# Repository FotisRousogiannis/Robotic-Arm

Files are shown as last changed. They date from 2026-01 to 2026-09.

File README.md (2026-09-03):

# Robotic Arm — Διπλωματική Εργασία

Σχεδίαση και ανάπτυξη ενός **6-DOF ρομποτικού βραχίονα**, από τη μηχανική
κατασκευή (3D printing) και τα ηλεκτρονικά, μέχρι το λογισμικό ελέγχου.
Το repository αποτελεί το επίσημο αποθετήριο της διπλωματικής εργασίας και
συγκεντρώνει το σύνολο του υλικού: μηχανολογικά σχέδια, hardware,
ηλεκτρικά/ηλεκτρονικά, τεκμηρίωση και αναφορές (reports).

---

## Στόχος του Project

Η μελέτη, σχεδίαση και υλοποίηση ενός λειτουργικού ρομποτικού βραχίονα
χαμηλού κόστους, με:

- Κατασκευή εξαρτημάτων μέσω **3D εκτύπωσης (FDM)**
- Κίνηση αρθρώσεων με **servo κινητήρες υψηλής ροπής (40 kg·cm)**
- Έλεγχο μέσω **Raspberry Pi 4** και οδηγό servo **PCA9685 (I²C, 16 κανάλια)**
- Τεκμηρίωση σε τρεις άξονες: μηχανολογικό, ηλεκτρικό και λογισμικό

---

## Δομή του Repository

```
.
├── Robotic_Arm_Project/
│   ├── 3D printing/          # STL / 3MF αρχεία προς εκτύπωση ανά εξάρτημα
│   │   ├── Rotating Base/    #   περιστρεφόμενη βάση
│   │   ├── Big Base/         #   κύρια βάση
│   │   ├── Bone 1/, Bone 2/  #   βραχίονες (links)
│   │   ├── Gears/            #   γρανάζια
│   │   ├── Timing Belt/      #   σύστημα ιμάντα
│   │   ├── Bearing holders/  #   στηρίγματα ρουλεμάν
│   │   ├── Electronics Holder/
│   │   ├── End Effector/     #   αρπάγη (gripper)
│   │   └── Caps/
│   ├── Hardware/             # Λίστα ηλεκτρικών εξαρτημάτων & datasheets
│   ├── Electrical/           # Σχηματικά διαγράμματα (schematics)
│   └── Documentation/        # Ρυθμίσεις slicer & τεκμηρίωση λογισμικού
├── Reports/                  # Mechanical / Electrical / Software reports (PDF)
├── Papers/                   # Σχετική βιβλιογραφία & ROS stack overview
└── README.md
```

---

## Hardware

### Τροφοδοσία
- 1× KUAIQU SPS-C3010 ρυθμιζόμενο τροφοδοτικό 30 V / 10 A / 300 W
- 2× XY5008E DC-DC Buck converter (CC/CV, 6–55 V, 5 A)

### Έλεγχος & Λογική
- 1× Raspberry Pi 4 Model B (4 GB)
- 1× PCA9685 — 16-channel 12-bit PWM servo driver (I²C)

### Κινητήρες (Servo)
Χρησιμοποιούνται servo **GXservo 40 kg·cm (MG)**:

| Άρθρωση | Πλήθος | Τύπος |
|---|---|---|
| Base | 1× | 40 kg·cm, 180° |
| Bone 1 | 4× | 40 kg·cm, 180° |
| Bone 2 | 4× | 40 kg·cm, 270° |
| End effector | 3× | 40 kg·cm, 180° |

### Καλωδίωση
- Σήμα: 3-pin, 22 AWG
- Ισχύς: 2-pin (κόκκινο/μαύρο), 18 AWG

> Αναλυτικά: [`Robotic_Arm_Project/Hardware/Electrical Components.md`](Robotic_Arm_Project/Hardware/Electrical%20Components.md)

---

## Κατασκευή (3D Printing)

Όλα τα δομικά εξαρτήματα βρίσκονται ως αρχεία `.stl` / `.3mf` στον φάκελο
`Robotic_Arm_Project/3D printing/`. Οι ρυθμίσεις slicer (Orca Slicer) που
χρησιμοποιήθηκαν βρίσκονται στο
`Robotic_Arm_Project/Documentation/`.

---

## Τεκμηρίωση & Αναφορές

Στον φάκελο `Reports/` υπάρχουν τρεις αναφορές:
- **Mechanical Report** — μηχανολογικός σχεδιασμός
- **Electrical Report** — ηλεκτρικό/ηλεκτρονικό υποσύστημα
- **Software Report** — λογισμικό ελέγχου

---

## Κατάσταση / Roadmap

- [x] Μηχανολογικός σχεδιασμός & 3D εκτύπωση εξαρτημάτων
- [x] Επιλογή ηλεκτρικών/ηλεκτρονικών εξαρτημάτων
- [x] Σχηματικά διαγράμματα
- [ ] Λογισμικό ελέγχου (kinematics, control)
- [ ] Ολοκλήρωση & δοκιμές συναρμολογημένου βραχίονα

---

## Άδεια χρήσης

Ακαδημαϊκή εργασία. Για χρήση/αναπαραγωγή επικοινωνήστε με τον συγγραφέα.

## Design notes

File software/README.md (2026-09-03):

# Software

The arm's software is organized in two tracks so you can move fast now
and still build the proper stack for the thesis.

```
software/
├── firmware/       # ESP32 firmware — the on-board control per segment PCB.
│   └── segment_controller/   PCA9685 + TCA9548A + AS5600, serial protocol.
├── tools/          # Standalone scripts — NO ROS needed. Quick bench test
│   └── servo_test.py   of a servo/gearbox straight off a PCA9685.
└── ros2_ws/        # ROS 2 workspace — the host-side coordination stack.
    └── src/robotic_arm_driver/
```

The real control is **distributed**: each segment PCB runs
`firmware/segment_controller` on its ESP32 (servo drive + encoder
feedback), and the ROS 2 host coordinates all segments. See
[`../docs/ARCHITECTURE.md`](../docs/ARCHITECTURE.md) for the topology.
`tools/servo_test.py` is only for quick bench checks before the boards
are wired in.

## Track 1 — Quick hardware tests (no ROS)

Goal right now: **verify the wrist and its gearboxes** before building
Link 1. `tools/servo_test.py` drives the PCA9685 directly.

### On the Raspberry Pi — Ubuntu Server (once)
Ubuntu Server has no `raspi-config`; enable I²C via the firmware config:
```bash
sudo nano /boot/firmware/config.txt      # add:  dtparam=i2c_arm=on
sudo apt install -y i2c-tools python3-pip
sudo usermod -aG i2c $USER               # then log out/in
sudo reboot
# after reboot:
pip install adafruit-circuitpython-pca9685 adafruit-blinka
i2cdetect -y 1                           # should show PCA9685 at 0x40
```

> Note: in the final design the ESP32 on each PCB drives the PCA9685, not
> the Pi. This direct-from-Pi path is only for quick bench testing of a
> servo/gearbox before the boards are in the loop.

### Test sequence (start gentle!)
```bash
cd software/tools

# 1. Center the wrist servos (find your real centers first):
python3 servo_test.py center --channels 8 9 10 11 --min 0 --max 270

# 2. Move ONE servo a little and confirm direction:
python3 servo_test.py set --channel 9 --angle 135 --min 0 --max 270

# 3. Slow, small sweep to watch a gearbox for binding/backlash:
python3 servo_test.py sweep --channel 9 --min 0 --max 270 \
        --start 120 --end 150 --step 2 --dwell 0.1

# 4. Differential check (wrist pitch/roll from 2 servos):
python3 servo_test.py diff --a 9 --b 10 --pitch 15 --roll 0   # pure pitch
python3 servo_test.py diff --a 9 --b 10 --pitch 0  --roll 15  # pure roll

# 5. Release when done:
python3 servo_test.py release --channels 8 9 10 11
```

> Runs in **SIMULATION mode** (prints pulses) on any machine without the
> PCA9685 libs, so you can dry-run commands on your laptop first.

**Safety:** keep a hand on the power switch; stop immediately if a servo
stalls, buzzes, or a gearbox binds. Increase travel only once direction
and limits are confirmed.

Record the real centers / min / max you find — they become the
calibration values in the ROS 2 config below.

## Track 2 — ROS 2 stack

`ros2_ws/src/robotic_arm_driver` — a ROS 2 (rclpy) node that subscribes
to `/joint_commands` (`sensor_msgs/JointState`, degrees) and drives the
servos, with **differential mixing** for the base and wrist.

### Build & run (on the Pi, ROS 2 installed)
```bash
cd software/ros2_ws
colcon build --packages-select robotic_arm_driver
source install/setup.bash

# Wrist-only bring-up:
ros2 launch robotic_arm_driver wrist_test.launch.py

# Command the wrist pitch to 15 deg from another terminal:
ros2 topic pub --once /joint_commands sensor_msgs/msg/JointState \
  '{name: ["wrist_pitch"], position: [15.0]}'
```

Calibration lives in `config/wrist_test.yaml` (wrist only) and
`config/servo_config.yaml` (full arm). Update the channel numbers,
centers, gains and pulse limits from what you measured in Track 1.

See [`../docs/ARCHITECTURE.md`](../docs/ARCHITECTURE.md) for the DOF map,
differential mixing math, and roadmap.

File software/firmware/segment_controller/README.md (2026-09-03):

# Segment Controller (ESP32 firmware)

One firmware for every per-segment PCB (base, wrist, ...). Each board runs
the local control loop for its joints:

- **PCA9685** → servo PWM
- **TCA9548A** → I²C mux selecting one **AS5600** encoder at a time
- **AS5600** → true joint-angle feedback (all share address `0x36`, so the
  mux is required)

It exposes a simple **serial protocol** (USB, 115200 baud) so you can test
the wrist and gearboxes right away, before any host/ROS integration.

## Build & flash (PlatformIO)
```bash
cd software/firmware/segment_controller
pio run                 # build
pio run -t upload       # flash the ESP32
pio device monitor      # open serial monitor @115200
```

Configure the board via `-DSEGMENT_NAME=...` in `platformio.ini` and the
wiring/limits in `include/config.h`.

## Serial commands
| Command | Action |
|---|---|
| `?` | print segment info (axes, channels) |
| `P <axis> <deg>` | set target angle for one axis (open-loop servo) |
| `H` | home all axes (servo center) |
| `E` | print all encoder angles (deg) |
| `M <a> <b> <p> <r>` | differential mix test: servos a,b from pitch/roll |
| `R <axis>` | release one axis servo (stop PWM) |

### Example wrist bring-up
```
?                 # confirm wiring
E                 # read encoders — move a joint by hand, watch it change
P 0 90            # command axis 0
M 0 1 15 0        # differential: pure pitch on servos ch0/ch1
M 0 1 0 15        # differential: pure roll
E                 # compare commanded vs actual (encoder) angle
```

## Calibration workflow
1. Flash, open the monitor, send `?` and `E`.
2. Turn each joint by hand and confirm the right encoder responds and the
   direction is correct (set `encoder_invert` in `config.h` if not).
3. Note the encoder reading at the mechanical home → set `encoder_offset`.
4. Command small servo angles with `P`; find the real `pulse_min/max` and
   `servo_min/max_angle` for each axis.
5. Copy the confirmed numbers into `config.h` (and the ROS 2 configs).

## Roadmap
- [ ] Closed-loop position control on the ESP32 (PID: encoder → servo)
- [ ] Host link via **micro-ROS** (`env:esp32-microros` in `platformio.ini`):
      each ESP32 is a ROS 2 node; host runs the micro-ROS Agent
      (`ros2 run micro_ros_agent micro_ros_agent udp4 --port 8888`).
- [ ] Publish `/<seg>/joint_states`, subscribe `/<seg>/joint_commands`

> Firmware/PCB work is on hold until the boards are built — the serial
> firmware above is enough for current bench testing.

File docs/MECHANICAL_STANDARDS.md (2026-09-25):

# Mechanical Standards

Standardization rules so every part interfaces cleanly and future parts
"just fit". Apply these across all segments. Items marked ❓ need
confirmation against existing parts.

---

## 0. Material assignment policy
**Default PLA+; PC only where extreme strength/heat is needed; TPU for
flexible parts.** Rule: *carries the load/torque or gets hot → PC; else PLA+.*

| Material | Parts |
|---|---|
| **PC** | all gears (planetary sun/planet/ring — esp. output stage; bevel), planet carrier, output/spline hubs, load-critical links, anything next to the servo (heat) |
| **PLA+** | covers, electronics holders, sensor mounts, brackets, non-load structure, prototypes |
| **TPU** | gripper pads/fingertips, feet, cable strain-relief, dampers/bushings |

> ⚠️ PLA+ **creeps** under sustained load and softens near heat (Tg ~60°C).
> Keep it off gears, shafts/hubs, and the main load-bearing links.

## 1. Fasteners
- **Socket head cap screws, ISO 4762 (DIN 912)**, metric, throughout.
- **M3** = primary · **M4 / M5** = structural / high-load.
- 3D-printed parts: **brass heat-set inserts (M3)** — never a screw straight
  into plastic.

## 2. Bearings (deep-groove ball, 2RS sealed)
Standardize on the set already in use:

| Bearing | bore × OD × W (mm) | Use (actual) |
|---|---|---|
| 6002 2RS | 15 × 32 × 9 | **planet gears** (each planet rotates on a 6002) |
| 6005 2RS | 25 × 47 × 12 | **shafts / joint output axes** (Ø25) |
| 6902 2RS | 15 × 28 × 7 | ❓ (thin-section, TBD) |
| 6004 2RS | 20 × 42 × 12 | ❓ TBD |
| 6208 2RS | 40 × 80 × 18 | ❓ likely base main rotation, TBD |

## 3. Shafts / hubs
- **Shaft Ø = bearing bore**, tolerance **h7** (slip/press per fit needed).
- Large bores (≥20) → **hub-in-bore** (bearing = joint pivot; hub rotates on
  inner race), leaving the bore **hollow for cable routing**.
- A **flat / D-cut** where a set-screw lands, to prevent slip.

| Element | Ø (=bore) | Bearing |
|---|---|---|
| output / joint shaft | 25 | 6005 |
| planet gear | 15 | 6002 |
| base main rotation | 40 | 6208 (TBD) |

## 4. Gears — global rules
- **Pressure angle: 20°** everywhere (non-negotiable for meshing).
- **Module: keep to few values.** Gears of different module DO NOT mesh.
  - Planetary gears: **helical, normal module mₙ = 1, helix 30°** (actual).
  - **Min ~17 teeth** on a pinion for spur; helical tolerates fewer (sun is
    16T helical — OK thanks to the helix angle raising virtual tooth count).
- **Center distance**: `C = module × (z₁ + z₂) / 2`.
- Printed material: **PETG** ok, **Nylon (PA)** preferred for loaded gears.

### 4a. Planetary gearbox (per joint) — ACTUAL design
2-stage, **1:6 × 1:6 = 1:36**. **Helical gears, 30° helix angle.**

| Element | Teeth | Hand | File |
|---|---|---|---|
| Sun | 16 | L | Sun Helical Gear (16L@30.00) |
| Planet (×3) | 32 | R | Healical Gear (32R@30.00) |
| Ring | 80 | R | Ring Gear |

- **Normal module mₙ = 1**, **helix angle β = 30°**, 20° PA.
- Ratio = 1 + 80/16 = **6.0** ✅ · 3 planets: (16+80)/3 = 32 ✓
- Helix hand: sun L, planet R (external mesh = opposite), ring R (internal =
  same as planet) ✓
- Transverse module mₜ = mₙ/cos β = 1/cos30° = **1.1547**.
  Pitch diameters (d = mₜ·z): sun 18.48 · planet 36.95 · ring 92.38 mm.
  Center distance sun↔planet = (18.48+36.95)/2 = **27.7 mm**
  = (ring−planet)/2 ✓ consistent.
- Helical gears create **axial thrust** — deep-groove bearings absorb it;
  keep it in mind for shaft location.
- Housing parts (CAD): Ring Gear, Planet Carrier, Planet Carrier Rotating
  Base, Cap, Servo holder, Servo Cap, servo arm cap.

### 4b. Bevel gears (differentials)
- **1:1 miter**, 90°, 20° PA, pitch diameter **Ø100 mm**.
- Bore = DIN 5480 internal spline (mounts on the gearbox output shaft).
- Current **module 1, z100** is **undersized for 5 kg** (tooth force ~740 N
  operating needs ~55 mm face at m1 — impossible).
- **Target spec (5 kg): module 2.5, z40 (keeps Ø100), face ~15–18 mm,
  PC** (available; strong + high Tg ~147°C) or PA-CF, face ~18 mm + firmware torque limit. See MECHANICAL_ANALYSIS.md.

## 5. Couplings & interfaces
- **Output shaft → bevel gear**: spline (see §9a) — carries actuator torque
  into the differential.
- **Gearbox housing → arm body**: ISO 9409-1 flange (see §9b).
- **Servo output spline: 25T** (standard for 35–40 kg standard-size servos;
  spline Ø ≈ 5.9 mm — confirm by counting teeth / checking the horns) →
  standard **25T spline hub / disc horn** as the servo interface everywhere.
- **servo → sun gear**: uses the **stock metal servo horn** (25T, included
  with the servo). The sun gear (or a printed adapter) bolts onto the horn
  through its screw holes — no separate hub needed. Standardize the sun/
  adapter to match the horn's bolt pattern.
- **shaft ↔ shaft**: **clamp-type coupling** (no backlash) sized to shaft Ø,
  preferred over set-screw for precision.

## 6. Differential flanges
- **Common bolt pattern**: proposed **6 × M3 on PCD 30 mm**, identical on base
  and wrist → interchangeable flanges.
- **Spigot centering** (a locating lip) for alignment — not screws alone.

## 7. Tolerances & fits
- Shaft/bearing: **h7** shaft into bearing bore.
- Gear backlash (printed): target **0.10–0.15 mm** (set as CAD offset).

## 8. File naming convention (gears & shafts)
Encode the spec in the filename so mating parts are obvious:
```
spur_m1.5_z22_b25_PA20.stl      spur, module 1.5, 22T, bore 25, PA 20°
bevel_m1.5_z20_90deg_b25.stl    bevel, module 1.5, 20T, 90°, bore 25
planet_m1.0_z24_sun12_ring60.stl
shaft_d25_L120_h7.stl           shaft Ø25, length 120, h7
```

## 9. Output interfaces — ISO

Two distinct interfaces per actuator:
```
servo → planetary(1:36) → OUTPUT SHAFT ──[spline]──► BEVEL gear → differential
                          gearbox housing ──[FLANGE ISO 9409-1]──► arm body (mount)
```

### 9a. Output shaft → bevel gear (torque path)
Drives the differential's bevel gear — **backlash & centering are critical**
here (differential mixing degrades with play), so **spline preferred over
key**.
**All parts are 3D printed** → the bevel gear's bore is a **printed internal
DIN 5480 spline** that slides onto the shaft's splined section. No press fit
(cracks/creeps printed plastic), no coupling, no locking device needed.

The shaft has two sections: a plain **Ø25 k6 journal** for the 6005 bearing,
and a **splined section** where the bevel gear mounts (spline is NOT at the
bearing seat).

### DIN 5480 spline values — from SplineCALC (DIN preferred pair)
**Designation: `DIN 5480 – 25 × 1.25 × 18 × 9H/8f`** (30° PA)

| Parameter | Shaft (external, 8f) | Hub / bevel bore (internal, 9H) |
|---|---|---|
| Reference diameter dB | 25.000 | 25.000 |
| Module m | 1.25 | 1.25 |
| Teeth z | 18 | 18 |
| Addendum mod. x | **+0.450** | **−0.450** |
| Pitch diameter d | 22.500 | 22.500 |
| Base diameter db | 19.486 | 19.486 |
| Tip diameter da | 24.750 | 22.500 |
| Root diameter df | 22.444 | 25.250 |
| Engagement length Le | 15 mm | 15 mm |
| Backlash j (min/max) | 0.038 / 0.284 mm | — |

- Chosen over m1/z24: **module 1.25 = coarser, stronger teeth** (better given
  the printed-gear strength concern).
- The 9H/8f pair already includes backlash (j = 0.038–0.284 mm); for 3D print
  add a touch more if it binds.
- Export the profile from SplineCALC (DXF shaft / DXF hub) straight into
  Fusion, or enter the values above.
- **Axial retention** (so the bevel doesn't slide off) — **as built**:
  a **heat-set insert (M4/M5) in the shaft end** + an **ISO 4762 screw +
  washer** through the bevel/cap that clamps it against a printed shoulder.
  Printed-friendly, no groove needed. (Alt: circlip DIN 471 Ø25.)
- Bearing seat: **Ø25 k6**; general tolerances ISO 2768-m; end chamfers 1×45°.

> Stay metric (DIN 5480, module-based). Avoid inch (McMaster) splined shafts
> — they force an inch-bore bearing at this seat.

> Spline chosen over a parallel key because it is printed anyway (no
> machining cost) and gives less backlash — important for clean pitch/roll
> decoupling in the differential. A DIN 6885 key remains a simpler fallback.

### 9b. Flange → arm body (mounting)
Mounts/reacts the gearbox housing to the arm structure — **ISO 9409-1**.
**Default: ISO 9409-1-50-4-M6**
- PCD **50 mm**, **4 × M6** (ISO 4762)
- centering **spigot H7/h7** (alignment by fit, not screws)
- Torque check (worst case 73.5 N·m): 73.5/0.025 = 2940 N ÷ 4 = **735 N/bolt**
  → M6 ample ✅
- Heavier option: **ISO 9409-1-63-6-M6** (PCD 63, 6 × M6)

Use the same flange across base / wrist / links for interchangeability.

## 10. Standard parts — sourcing (CAD)
Pull ready, dimensioned models into Fusion; model only custom parts.

| Part | Standard | Source (Fusion) |
|---|---|---|
| Bearings (6002/6005/6208…) | ISO | McMaster (Insert → McMaster-Carr) / TraceParts / Misumi |
| Screws (M3–M6 socket head) | ISO 4762 | McMaster / Fusion fastener lib / TraceParts |
| Parallel key 8×7 | DIN 6885-1 | TraceParts / Misumi |
| Precision shaft Ø25 k6 | ISO 286 | McMaster / Misumi (configurable) |
| Heat-set inserts M3 | — | McMaster |
| **ISO 9409-1 flange** | ISO 9409-1 | **model in Fusion** (spec, not a purchased part) |
| Gears (planetary/bevel) | — | model in Fusion (per §4) |

## 11. I²C address map (electronics, for reference)
| Device | Address |
|---|---|
| PCA9685 (PWM) | 0x40 |
| ADS1115 (ADC) | 0x48 |
| TCA9548A (mux) | 0x70 |
| AS5600 (encoder) | 0x36 (behind mux) |

---

## Confirmed
- [x] Planetary: helical, mₙ=1, 30° helix, sun 16 / planet 32 (×3) / ring 80
- [x] Planet count: 3

## Confirmed (cont.)
- [x] Servo interface: stock metal 25T horn drives the sun gear
- [x] Servo spline: 25T

## Open items to confirm
- [ ] Output torque path: parallel key vs direct-through-flange
- [ ] Flange size: ISO 9409-1-50-4-M6 (default) vs 63-6-M6
- [ ] Bevel gear module/teeth (needs differential envelope)
- [ ] Placement of remaining bearings (6208 / 6004 / 6902)
- [ ] Planet gear face width (for tooth-stress recheck)

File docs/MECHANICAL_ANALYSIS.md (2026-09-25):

# Mechanical Analysis

Engineering analysis of the actuator/drivetrain against the design targets.
All figures are estimates for design guidance; validate on hardware.

## Inputs (from BOM / standards)
| Parameter | Value |
|---|---|
| Servo | QY3240MG, ~40 kg·cm ≈ **3.9 N·m stall**, continuous rotation |
| Servo free speed | ~300°/s (≈50 rpm) |
| Gearbox | 2-stage planetary, **1:6 × 1:6 = 1:36** |
| Efficiency (2 stages) | ~0.8 assumed |
| Differential | pitch uses **2 actuators** (torques add) |
| Arm self-weight | 5 kg, CoM ≈ 0.5 m |
| Target reach | 1.0 m |
| **Target payload** | **5 kg @ 1 m** |

## 1. Output speed & torque (per actuator, 1:36)
- Speed: 300 / 36 = **8.3°/s** (90° in ~11 s)
- Torque stall: 3.9 × 36 × 0.8 = **~112 N·m**
- Torque continuous (≈stall/3): **~37 N·m**

Differential (pitch, ×2):
| | per actuator | differential (×2) |
|--|---|---|
| Stall | 112 N·m | **214 N·m** |
| Continuous | 37 N·m | **75 N·m** |

## 2. Torque required for 5 kg @ 1 m (worst case, horizontal)
| Component | Moment |
|---|---|
| Payload 5 kg × 1.0 m | 49 N·m |
| Arm 5 kg × 0.5 m | 24.5 N·m |
| **Total** | **73.5 N·m** |

## 3. Does 1:36 meet it?
| Mode | Available (diff) | vs 73.5 N·m |
|---|---|---|
| Stall (momentary) | 214 N·m | SF ≈ 2.9 ✅ |
| Intermittent (~50% duty, pick-place) | ~112 N·m | SF ≈ 1.5 ✅ |
| Continuous hold (stall/3) | 75 N·m | SF ≈ 1.0 🟠 marginal |

**Conclusion:** 1:36 is the **right reduction** for 5 kg pick-and-place.
Lower ratios can't even hold the arm's own weight continuously; higher
ratios (1:48) hold better but are too slow (~6°/s) and worsen gear stress.
Continuous indefinite holding of 5 kg is marginal → needs a holding
strategy (§6).

### Reduction trade-off (continuous payload @1 m)
| Ratio | Output speed | Continuous payload | Gear stress |
|---|---|---|---|
| 1:18 | 17°/s | ~1.3 kg | medium |
| 1:24 | 12.5°/s | ~2.6 kg | high |
| **1:36** | 8.3°/s | ~5 kg | 🔴 very high |

## 4. Gear tooth loading (the critical issue)
Output stage transmits the full torque. Tangential force at the
planet↔ring mesh (pitch r_ring = 46.2 mm, 3 planets sharing):

    F_t = T / (r_ring × n_planets)
        = 141 N·m / (0.0462 m × 3) ≈ 1020 N per planet (at stall)
    (continuous ≈ 340 N)

On **module 1 printed teeth** this is very high — PLA/PETG teeth risk
shearing near stall/shock. **This is the real limit, not the ratio.**

Lewis check (σ = F_t / (b·m·Y), Y≈0.36 for 32T):
- To keep stress reasonable, either raise **module**, widen **face (b)**,
  or use a stronger **material** — strength scales with **b·m·material**.

### Fixes (output stage)
1. **Material: Nylon / PA-CF (or POM)** instead of PLA/PETG — 3–5× strength
   and far better wear. Biggest single win.
2. **Increase face width** — strength rises linearly with b; keeps the
   16/32/80 geometry unchanged (gears just get thicker).
3. **Firmware torque/current limit** — never approach stall.
4. (Optional) larger module **only on the output stage** if 1+2 aren't enough.

## 5. Helical thrust
Helix angle **30°** is high (typical 15–20°). Axial thrust:

    F_axial = F_t × tan(30°) ≈ 1020 × 0.577 ≈ 590 N per planet (stall)

Deep-groove 6002 bearings take limited axial load (~25% of radial).
**Recommendation:** reduce helix to **15–20°** to cut thrust, or ensure
adequate axial support.

## 6. Holding 5 kg without cooking the servos
A continuous-rotation servo holding a load stalls against it → heat.
Options:
- **Mechanical brake** on the joint (best for sustained holds).
- **Self-locking element** (e.g. a worm stage) if a redesign is acceptable.
- **Limit duty cycle** — fine if the arm mostly moves, rarely holds long.
- Rely on the **1:36 back-drive resistance** (helps but not self-locking).

## 7. Secondary notes
- **Planet wall thickness:** planet 32T m1 → root Ø ≈ 34 mm vs 6002 OD 32 mm
  → ~1 mm wall under the teeth. Consider a smaller-OD planet bearing
  (e.g. 6802/688) or a larger planet for more material.
- **Backlash** accumulates over 2 stages + differential; the output AS5600
  (closed loop) compensates static error but not reversal backlash.

## Differential bevel gears — sizing for 5 kg
Bevel tooth force (pitch r = 50 mm): **~740 N operating**, ~2240 N stall.
Face limit on a Ø100 miter = cone distance/3 ≈ 23.6 mm.

Required face width vs module (keep Ø100):
| Module | z (Ø100) | Nylon σ30 | PA-CF σ50 |
|---|---|---|---|
| 1 (current) | 100 | ~55 mm ❌ | ~33 mm ❌ |
| 2 | 50 | ~29 mm 🟠 | ~17 mm ✅ |
| **2.5** | **40** | ~23 mm 🟠 | **~14 mm ✅** |
| 3 | 33 | ~20 mm ✅ | ~12 mm ✅ |

**Recommended (keeps Ø100, 1:1 miter, 5 kg target):** bevel **module 2.5,
z=40, 20° PA**, face **~18 mm**, **PC** (available; σ≈40 MPa, high Tg ~147°C
resists servo heat) + firmware torque limit. Module 1 is undersized at any
practical face — raise the module, not the diameter. PC prints hot (~270°C,
enclosure); add PTFE grease or use PC-CF for better wear.

Levers (any/all): ↑module (2.5–3), ↑face (≤23 mm), PA-CF material, ↑bevel
diameter (Ø150 → F_t ≈ 490 N so m2 suffices), torque limit.

## Summary — required changes for 5 kg
| # | Change | Priority |
|---|---|---|
| 1 | **Bevel gears → module 2.5, z40 (keep Ø100), face ~15–18 mm, PA-CF** | 🔴 must |
| 2 | Planetary output stage → higher module / PA-CF + wider face | 🔴 must |
| 3 | Holding strategy (brake / duty limit) | 🔴 must for sustained hold |
| 4 | Firmware torque/current limit | 🔴 must (caps stall spikes) |
| 5 | Reduce helix to 15–20° | 🟠 recommended |
| 6 | Reduce arm weight / mass near base | 🟢 improves margin & speed |
| — | **Keep 1:36 reduction & Ø100 bevel diameter** | ✅ optimal for 5 kg |

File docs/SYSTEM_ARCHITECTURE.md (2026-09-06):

# System Architecture — Distributed ROS 2 + UI

Target architecture for the robotic arm: a **distributed ROS 2 system**
where a workstation does the heavy compute, a Raspberry Pi rides onboard as
a node/bridge, and each arm segment is driven by an ESP32 running
micro-ROS. A web dashboard controls everything and hosts manual and
autonomous (VLM) modes.

## Compute layers

```
┌──────────────── Clients: browsers (laptop / phone / tablet) ─────────────┐
│  thin — just open the URL, no install; download the dashboard            │
└───────────────────────────────┬─────────────────────────────────────────┘
                                 │ WebSocket (rosbridge) + MJPEG (camera)
┌────────────────── Workstation (MAIN COMPUTE) ────────────────────────────┐
│  ROS 2                                                                    │
│   • web dashboard server (rosbridge_server, web_video_server / app)       │
│   • mode_manager        — arbitrates who commands the arm                 │
│   • vlm_agent           — camera + goal -> high-level actions (autonomous)│
│   • motion / kinematics — FK/IK, planning                                 │
│   • simulation          — URDF in RViz / Gazebo / Foxglove                │
└───────────────────────────────┬─────────────────────────────────────────┘
                                 │ ROS 2 DDS (same domain, WiFi/LAN)
┌────────────────── Raspberry Pi (ONBOARD NODE / BRIDGE) ───────────────────┐
│  ROS 2                                                                    │
│   • micro-ROS Agent     — bridges the ESP32 nodes onto the graph          │
│   • camera node         — publishes /camera/image                         │
│   • (future) onboard brain for standalone autonomy                        │
└───────────────────────────────┬─────────────────────────────────────────┘
                     micro-ROS (XRCE-DDS over WiFi/UDP or serial)
        ┌────────────────────────┼────────────────────────┐
   ┌────┴─────┐            ┌──────┴─────┐            ┌──────┴─────┐
   │ESP32 base│            │ESP32 wrist │            │ ESP32 ...  │   per-segment nodes
   │ PCA9685  │            │ PCA9685    │            │            │
   │ TCA9548  │            │ TCA9548    │            │            │
   │ AS5600 x │            │ AS5600 x   │            │            │
   └──────────┘            └────────────┘            └────────────┘
     servos + encoders, local closed-loop control
```

## Who runs what

| Layer | Runs on | Responsibilities |
|---|---|---|
| **Clients** | any browser | render dashboard, capture input — no install, nothing device-specific |
| **Main compute** | workstation/PC | ROS 2 brain: UI server, VLM, planning, kinematics, simulation, mode manager |
| **Onboard bridge** | Raspberry Pi (Ubuntu Server) | micro-ROS Agent, camera; keeps a path to standalone autonomy later |
| **Segment controllers** | ESP32 (one per PCB) | drive servos (PCA9685), read AS5600 via TCA9548, local position loop |

Why keep the Pi: it gives an **onboard ROS 2 presence** — the arm can carry
the micro-ROS Agent and camera locally, and later host an onboard brain for
standalone operation. The VLM stays on the workstation (or cloud): it is
too heavy for a Pi. For true onboard autonomy the Pi would be swapped for a
stronger board (e.g. Jetson) without changing the ROS graph.

## Communication (all ROS 2 native)

| Link | Protocol |
|---|---|
| node ↔ node (workstation ↔ Pi) | **DDS** (ROS 2 default, same domain over WiFi/LAN) |
| ESP32 ↔ Agent | **micro-ROS / XRCE-DDS** (WiFi/UDP, serial fallback) |
| browser ↔ ROS | **rosbridge** (WebSocket) + **web_video_server** (MJPEG) |

## Core topics (draft)

| Topic | Dir | Type |
|---|-----|---|
| `/<seg>/joint_commands` | →ESP32 | `sensor_msgs/JointState` (targets) |
| `/<seg>/joint_states` | ESP32→ | `sensor_msgs/JointState` (AS5600 feedback) |
| `/camera/image` | Pi→ | `sensor_msgs/Image` |
| `/mode` | UI→ | current mode (manual / autonomous / estop) |
| `/vlm/goal` | UI→ | natural-language task for the VLM |

## Modes

A `mode_manager` node arbitrates **who is allowed to publish commands**, so
manual and autonomous never fight:

- **Manual** — dashboard teleop drives `/joint_commands`.
- **Autonomous** — `vlm_agent` takes the camera + a goal and drives
  `/joint_commands`; the UI shows what it's doing.
- **E-stop** — everything neutral/stopped; overrides all.

## Reuse from the bench work

Everything already built carries over:
- **Calibration** (`software/tools/arm_calibration.json`): servo neutral
  1600 µs, range 500–2500, base = differential ch 0/1 (B inverted). These
  values move straight into the ESP32 firmware.
- **Differential mixing** (pitch = servos together, roll = servos opposed)
  becomes the per-segment logic in the ESP32 / `servo_driver`.
- **Bench tools** stay useful for quick hardware checks off-ROS.

## Phased plan

1. **Web teleop (now)** — dashboard skeleton controlling the base
   open-loop, structured to grow. Direct link today; swaps to ROS later.
2. **ROS bring-up** — servo/segment nodes + rosbridge; dashboard sends
   `/joint_commands`.
3. **Camera panel** — `web_video_server` MJPEG in the dashboard.
4. **Sim panel** — URDF in RViz/Foxglove or an embedded three.js viewer.
5. **micro-ROS on ESP32** — real per-segment controllers on the graph.
6. **Mode manager + VLM** — autonomous mode with the vision-language agent.

> Decision (locked): workstation = main compute; Raspberry Pi kept as the
> onboard ROS 2 node/bridge; ESP32 per segment via micro-ROS.

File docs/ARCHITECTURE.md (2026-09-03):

# Robotic Arm — Architecture

Single source of truth for the arm's mechanical, electrical and software
structure. Keep this file updated as the design evolves.

## Degrees of freedom

The arm targets **6 DOF** plus a gripper. It uses two **differential
mechanisms** (base and wrist): in each, two servos move together to
produce two rotational DOF.

| Segment | DOF | Mechanism | Status |
|---|-----|---|---|
| Base | 2 | Differential (pitch + roll) | ✅ built |
| Link 1 | 1 | (planned) | ❌ not built yet |
| Wrist | 3 | Differential (pitch + roll) + yaw | ✅ built |
| Gripper | 1 | Direct servo, camera mount  | ✅ built |

> Link 1 is intentionally left for last so the wrist can be tested and
> calibrated independently first. The base and the far end of the wrist
> share a similar differential design.

## Logical joints (`/joint_commands`)

Commands are `sensor_msgs/JointState`, positions in **degrees**, matched
by name:

- `base_pitch`, `base_roll`   → base differential (channels 0, 1)
- `wrist_pitch`, `wrist_roll` → wrist differential (channels 9, 10)
- `wrist_yaw`                  → direct servo (channel 8)
- `gripper`                   → direct servo (channel 11)

### Differential mixing

For a differential pair, the two motor angles are:

```
motor_A = center_a + pitch_gain * pitch + roll_gain * roll
motor_B = center_b + pitch_gain * pitch - roll_gain * roll
```

- Pure **pitch**: both motors rotate the same direction.
- Pure **roll**: motors rotate opposite directions.

`center_*`, `*_gain`, and the servo travel/pulse limits are calibrated
per mechanism in the config YAML.

## Control topology — distributed (ESP32 per segment)

Control is **distributed**: each topological segment of the arm carries
its own custom PCB with a local ESP32 controller. A central host (PC or
Raspberry Pi 4, running **Ubuntu Server** for native ROS 2) coordinates
all segments and runs the high-level stack; it does **not** drive servos
directly.

```
        ┌────────────────────────── Host (PC / Raspberry Pi 4) ──────────────────────────┐
        │   high-level control: targets out, joint state in, kinematics, planning        │
        └───────────────┬─────────────────────────────┬─────────────────────────────────┘
                        │ (micro-ROS)                 │ (micro-ROS)
             ┌──────────┴──────────┐        ┌─────────┴───────────┐
             │  Base PCB (ESP32)   │        │  Wrist PCB (ESP32)  │   ... one per segment
             │  joints 1, 2, 3     │        │  joints 4, 5, 6     │
             ├─────────────────────┤        ├─────────────────────┤
             │ PCA9685  → servos   │        │ PCA9685  → servos   │
             │ TCA9548A → AS5600   │        │ TCA9548A → AS5600   │
             │ buck converter      │        │ buck converter      │
             └─────────────────────┘        └─────────────────────┘
```

### Per-segment PCB
Each control PCB (e.g. the **base PCB** handling joints 1-2 differential +
joint 3) carries:

| Part | Role |
|---|---|
| **ESP32** | Local controller: closed-loop position control, host comms  |
| **PCA9685** | 16-ch PWM servo driver (I²C) |
| **TCA9548A**  | I²C multiplexer — lets several **AS5600** encoders share the bus (all fixed at 0x36) |
| **AS5600** | Magnetic encoder on each axis → true joint position feedback|
| **Buck conv.**| Steps supply down to logic / sensor voltages |

> Contact sensors on the gripper exist but are out of scope for now.

### Closed-loop position control
Unlike open-loop PWM, each ESP32 reads the **AS5600** angle on every axis
and can servo to a target position, compensating for gearbox backlash and
servo droop. Encoders sit behind the **TCA9548A** because every AS5600
answers at the same I²C address (0x36) — the ESP32 selects one mux channel
at a time to read each encoder.

### Host link — micro-ROS

Each ESP32 runs **micro-ROS**, so every segment PCB is a first-class ROS 2
node. The host (Ubuntu Server) runs the **micro-ROS Agent**, which bridges
the ESP32 nodes onto the normal ROS 2 graph.

```
ESP32 (base)  ──micro-ROS──┐
ESP32 (wrist) ──micro-ROS──┼──► micro-ROS Agent (host) ──► ROS 2 graph ──► robotic_arm_driver / MoveIt
ESP32 (...)   ──micro-ROS──┘        (UDP over WiFi, or serial)
```

Suggested per-segment interface (namespaced by segment):

| Topic | Dir | Type |
|---|---|---|
| `/<seg>/joint_commands` | host→ESP32| `sensor_msgs/JointState`  |
| `/<seg>/joint_states` | ESP32→host| `sensor_msgs/JointState`  (from AS5600) |

- **Transport**: UDP over WiFi keeps each PCB wireless (only power to the
  segment); serial is the fallback for bring-up/debug.
- The ESP32 keeps its **local closed loop** (AS5600 → servo); micro-ROS
  carries targets in and true positions out.
- Run the agent on the host, e.g.
  `ros2 run micro_ros_agent micro_ros_agent udp4 --port 8888`.

> The `segment_controller` firmware currently speaks a simple **serial**
> protocol for bench testing. The micro-ROS transport is layered on top of
> the same local control (see the firmware README roadmap).

## Electrical

- **Two isolated power rails** (built):
  1. Servo power — high-current rail for the GXservo motors
  2. Logic power — host + electronics (each PCB bucks down locally)
- **Servos**: GXservo 40 kg·cm (MG). See `Robotic_Arm_Project/Hardware/`.

> Keep the two grounds **commonly referenced** but the rails separate, so
> servo current transients don't brown out the logic / ESP32s.

## Software stack

- **Firmware — `software/firmware/`** (ESP32, per segment): drive servos
  via PCA9685, read AS5600 encoders through the TCA9548A, run the local
  position loop, talk to the host. *(link/protocol: to be decided)*
- **Bench tools — `software/tools/`**: standalone Python (no ROS) to
  test servos & gearboxes directly on a PCA9685 for quick checks.
- **Host — `software/ros2_ws/`**: ROS 2 stack that coordinates segments
  (`robotic_arm_driver` currently models differential mixing).
- **CAD**: Fusion 360 model (incomplete — Link 1 pending). Will be the
  source for the URDF once the geometry is finalized.
- Planned: URDF/description, kinematics (FK/IK), MoveIt, teleop, vision
  (gripper camera).

## Roadmap

1. ✅ Mechanical: base, wrist, gripper
2. ✅ Electrical: components, dual power rails
3. ▶️ **Software: drive & calibrate the wrist** (current)
4. ⬜ Build & integrate Link 1 → full 6-DOF
5. ⬜ URDF + kinematics
6. ⬜ Teleop / vision-based tasks

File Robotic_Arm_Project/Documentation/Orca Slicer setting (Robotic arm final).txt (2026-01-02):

pw 	    ok   expansion : circle -> outer(-0.05),inner(0.05) /rectangle -> outer(0),inner(0.1)
pz height   ok	 shrinkage : circle -> outer(0.05),inner(-0.05) /rectangle -> outer(0),inner(-0.1)
inner/outer ok

circle inner offset(constant)
circle outer offset(-0.1mm diameter /-0.05mm radius) lose fit
circle outer offset(-0.05mm diameter /-0.025mm radius) medium fit
circle outer offset(0.0mm diameter /0.00mm radius) tight fit

rectangle inner offset(constant)
rectangle outer offset(constant) -> medium-tight fit

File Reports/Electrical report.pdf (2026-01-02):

## Ηλεκτρολογικό και Ηλεκτρονικό Υποσύστημα Ρομποτικού Βραχίονα

### 1. Εισαγωγή

Στο παρόν κεφάλαιο παρουσιάζεται ο σχεδιασμός και η ανάλυση του ηλεκτρολογικού και ηλεκτρονικού υποσυστήματος ενός ρομποτικού βραχίονα έξι βαθμών ελευθερίας (6-DOF), ο οποίος υλοποιείται με ψηφιακούς servomotors υψηλής ροπής. Ο ηλεκτρικός σχεδιασμός αποτελεί κρίσιμο παράγοντα για την αξιόπιστη λειτουργία του συστήματος, καθώς καλείται να υποστηρίξει τόσο υψηλά παλμικά ρεύματα όσο και ευαίσθητα σήματα ελέγχου.

Βασικός στόχος του σχεδιασμού είναι η εξασφάλιση σταθερής τροφοδοσίας, η αποφυγή πτώσεων τάσης (voltage sag), η μείωση του ηλεκτρικού θορύβου και η ασφαλής διασύνδεση των επιμέρους υποσυστημάτων ελέγχου και ενεργοποίησης. Για τον σκοπό αυτό, το σύστημα διαχωρίζεται λειτουργικά σε δύο κύρια μέρη: το υποσύστημα ισχύος (Power Subsystem) και το υποσύστημα σημάτων ελέγχου (Signal Subsystem).

### 2. Συνολική Ηλεκτρική Αρχιτεκτονική

Η συνολική ηλεκτρική αρχιτεκτονική του ρομποτικού βραχίονα βασίζεται στον σαφή διαχωρισμό μεταξύ γραμμών ισχύος και γραμμών σημάτων. Η προσέγγιση αυτή επιτρέπει τη μείωση της ηλεκτρομαγνητικής σύζευξης μεταξύ των παλμικών φορτίων των κινητήρων και των κυκλωμάτων χαμηλής ισχύος.

Η κεντρική πηγή ισχύος του συστήματος είναι εργαστηριακή ρυθμιζόμενη τροφοδοσία συνεχούς τάσης, από την οποία παράγονται δύο ανεξάρτητα rails μέσω μετατροπέων τύπου buck:

- ένα rail στα 5V για την τροφοδοσία του υπολογιστικού συστήματος ελέγχου (Raspberry Pi 4),
- ένα rail στα 7.4V για την τροφοδοσία των servomotors και της γραμμής V+ του PWM driver PCA9685.

Ο διαχωρισμός αυτός είναι κρίσιμος, καθώς τα servomotors εμφανίζουν έντονα παλμικά ρεύματα, τα οποία θα μπορούσαν να προκαλέσουν αστάθεια ή επανεκκίνηση του Raspberry Pi αν τροφοδοτούνταν από κοινό rail.

### 3. Power Subsystem

### 3.1 Πηγή Τροφοδοσίας και Buck Converters

Η κύρια τροφοδοσία παρέχεται από εργαστηριακή ρυθμιζόμενη πηγή συνεχούς τάσης, η οποία επιτρέπει τον ακριβή έλεγχο της τάσης και του ρεύματος, καθώς και την ασφαλή δοκιμή του συστήματος σε διαφορετικά σενάρια φόρτισης. Από την πηγή αυτή, δύο μετατροπείς τύπου buck χρησιμοποιούνται για την παραγωγή των επιμέρους rails.

Ο πρώτος buck μετατρέπει την είσοδο σε σταθερή τάση 5V και τροφοδοτεί αποκλειστικά το Raspberry Pi 4. Ο δεύτερος buck μετατρέπει την είσοδο σε τάση 7.4V και τροφοδοτεί τους servomotors μέσω της γραμμής V+ του PCA9685. Ο δεύτερος μετατροπέας έχει ονομαστικό ρεύμα εξόδου 8A και αποτελεί το βασικό rail ισχύος του συστήματος.

3.2 5V Rail – Τροφοδοσία Raspberry Pi

Το 5V rail προορίζεται αποκλειστικά για το Raspberry Pi 4 και θεωρείται “clean logic rail”. Η ανεξάρτητη τροφοδοσία του υπολογιστικού συστήματος εξασφαλίζει σταθερή λειτουργία ακόμη και σε περιπτώσεις έντονης κινητικής δραστηριότητας του ρομποτικού βραχίονα.

Η απομόνωση αυτή αποτρέπει φαινόμενα υποβιβασμού τάσης (brownout) και αυξάνει τη συνολική αξιοπιστία του συστήματος ελέγχου, ιδιαίτερα κατά τη διάρκεια απότομων μεταβατικών καταστάσεων των κινητήρων.

3.3 7.4V Rail – Τροφοδοσία Servomotors

Το 7.4V rail τροφοδοτεί όλους τους servomotors του ρομποτικού βραχίονα καθώς και τη γραμμή V+ του PCA9685. Οι χρησιμοποιούμενοι ψηφιακοί servomotors έχουν ονομαστική τάση λειτουργίας 6.0–7.4V και stall current έως 3.2A στα 7.4V.

Δεδομένου ότι στο σύστημα χρησιμοποιούνται συνολικά δώδεκα servomotors, η θεωρητική ταυτόχρονη κατανάλωση σε συνθήκες stall υπερβαίνει κατά πολύ τις δυνατότητες του buck converter. Ωστόσο, η ταυτόχρονη λειτουργία όλων των κινητήρων σε κατάσταση stall θεωρείται εξαιρετικά απίθανη σε κανονικές συνθήκες λειτουργίας.

Για τον λόγο αυτό, ο σχεδιασμός βασίζεται σε ρεαλιστικά σενάρια λειτουργίας, στα οποία μόνο υποσύνολα κινητήρων φτάνουν σε υψηλή φόρτιση ταυτόχρονα, ενώ οι υπόλοιποι λειτουργούν σε χαμηλότερα επίπεδα ρεύματος.

### 4. Ανάλυση Ρευμάτων και Ισχύος

Η ανάλυση ρευμάτων βασίζεται στα χαρακτηριστικά των servomotors και στη φύση της κινηματικής του ρομποτικού βραχίονα. Το stall current κάθε servo αποτελεί ανώτατο όριο και χρησιμοποιείται κυρίως για τον προσδιορισμό των στιγμιαίων αιχμών ρεύματος.

Σε τυπικές συνθήκες λειτουργίας, το ρεύμα ανά servo είναι σημαντικά χαμηλότερο από το stall current και εξαρτάται από το φορτίο, την επιτάχυνση και τη ροπή που απαιτείται σε κάθε άρθρωση. Για τον προσδιορισμό των απαιτήσεων του 7.4V rail, εξετάζονται σενάρια στα οποία τέσσερις έως έξι κινητήρες ενδέχεται να εμφανίσουν αυξημένη κατανάλωση ταυτόχρονα.

Με βάση τα σενάρια αυτά, το buck converter των 8A μπορεί να υποστηρίξει την τυπική συνεχή λειτουργία του συστήματος, ενώ οι στιγμιαίες αιχμές ρεύματος αντιμετωπίζονται με τη χρήση τεχνικών απορρόφησης και διαχείρισης φορτίου.

### 5. Διαχείριση Αιχμών Ρεύματος

Η διαχείριση των αιχμών ρεύματος αποτελεί κρίσιμο στοιχείο του σχεδιασμού. Για τον σκοπό αυτό, χρησιμοποιούνται τόσο υλικές όσο και λογισμικές τεχνικές.

Σε επίπεδο υλικού, προβλέπεται η χρήση πυκνωτών μεγάλης χωρητικότητας (bulk capacitance) κοντά στο σημείο διανομής της γραμμής 7.4V, ώστε να παρέχεται τοπική αποθήκευση ενέργειας κατά τη διάρκεια στιγμιαίων αυξήσεων φορτίου. Η προσέγγιση αυτή μειώνει την πτώση τάσης στο rail και περιορίζει την καταπόνηση του buck converter.

Σε επίπεδο λογισμικού, η κίνηση των αρθρώσεων σχεδιάζεται ώστε να αποφεύγονται απότομες ταυτόχρονες επιταχύνσεις πολλών αξόνων. Ο περιορισμός της επιτάχυνσης και του ρυθμού μεταβολής της (jerk limiting) μειώνει την πιθανότητα εμφάνισης ταυτόχρονων peak currents.

### 6. Signal Subsystem

### 6.1 Επικοινωνία Raspberry Pi – PCA9685

Ο έλεγχος των servomotors υλοποιείται μέσω του PWM driver PCA9685, ο οποίος επικοινωνεί με το Raspberry Pi 4 μέσω του διαύλου I2C. Ο δίαυλος αυτός επιτρέπει τον έλεγχο πολλαπλών καναλιών PWM με ελάχιστη χρήση ακροδεκτών στο Raspberry Pi.

Η σωστή δρομολόγηση των γραμμών SDA και SCL, σε συνδυασμό με κοινή αναφορά γείωσης, είναι απαραίτητη για την αξιόπιστη επικοινωνία μεταξύ των δύο συστημάτων.

### 6.2 Παραγωγή PWM και Αντιστοίχιση Καναλιών

Το PCA9685 παράγει σήματα PWM για τον έλεγχο της γωνιακής θέσης των servomotors. Κάθε servo αντιστοιχίζεται σε συγκεκριμένο κανάλι PWM, σύμφωνα με τη μηχανική δομή του βραχίονα (βάση, βραχίονας, αντιβραχίονας, τελικό εργαλείο).

Η οργανωμένη αντιστοίχιση καναλιών διευκολύνει τόσο τον προγραμματισμό όσο και τη διαδικασία εντοπισμού σφαλμάτων (debugging).

### 6.3 Output Enable και Ασφάλεια

Το pin Output Enable του PCA9685 χρησιμοποιείται ως μηχανισμός ασφάλειας, επιτρέποντας την απενεργοποίηση όλων των εξόδων PWM σε περίπτωση εκκίνησης, σφάλματος ή ανάγκης έκτακτης διακοπής. Με τον τρόπο αυτό αποφεύγονται ανεπιθύμητες κινήσεις των κινητήρων κατά την ενεργοποίηση του συστήματος.

### 7. Καλωδίωση και Γείωση

Η καλωδίωση του συστήματος σχεδιάζεται με βάση τον διαχωρισμό μεταξύ γραμμών ισχύος και γραμμών σημάτων. Οι γραμμές τροφοδοσίας των servomotors υλοποιούνται με αγωγούς μεγαλύτερης διατομής, ενώ οι γραμμές σημάτων διατηρούνται όσο το δυνατόν πιο σύντομες και απομονωμένες από τις γραμμές ισχύος.

Η γείωση υλοποιείται με κοινή αναφορά για όλα τα υποσυστήματα, αλλά με προσεκτική δρομολόγηση των ρευμάτων επιστροφής, ώστε τα μεγάλα ρεύματα των κινητήρων να μην διέρχονται από τα κυκλώματα λογικής.

### 8. Συμπεράσματα

Ο ηλεκτρολογικός και ηλεκτρονικός σχεδιασμός του ρομποτικού βραχίονα βασίζεται σε σαφή διαχωρισμό ισχύος και σημάτων, τεκμηριωμένη ανάλυση ρευμάτων και χρήση τεχνικών διαχείρισης αιχμών φορτίου. Η επιλογή ανεξάρτητων rails, η χρήση buck converters και η προσεκτική καλωδίωση συμβάλλουν στη σταθερή και αξιόπιστη λειτουργία του συστήματος, παρέχοντας ένα κατάλληλο υπόβαθρο για περαιτέρω επέκταση και βελτιστοποίηση.

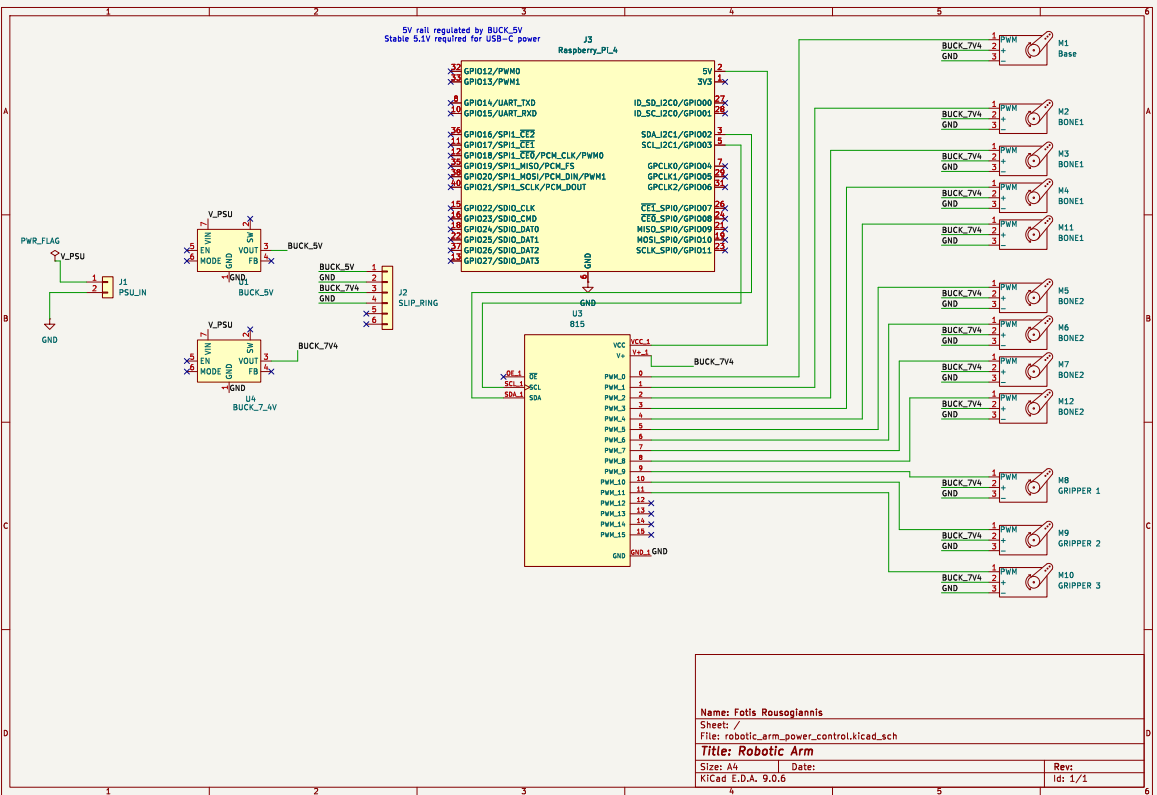
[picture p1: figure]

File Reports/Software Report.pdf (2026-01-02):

# Κεφάλαιο 3

## Λογισμική Αρχιτεκτονική και Λειτουργικές Απαιτήσεις του Ρομποτικού Βραχίονα

## 3.1 Εισαγωγή

Στο παρόν κεφάλαιο παρουσιάζεται η λογισμική αρχιτεκτονική του ρομποτικού βραχίονα και η αντιστοίχισή της με τις λειτουργικές απαιτήσεις του συστήματος.
Ο σχεδιασμός του λογισμικού βασίζεται στο ROS 2 (Robot Operating System 2) και ακολουθεί σύγχρονες αρχές ανάπτυξης ρομποτικών συστημάτων, με έμφαση στη δομική αρθρωτότητα (modularity), στον σαφή διαχωρισμό αρμοδιοτήτων και στη δυνατότητα επεκτασιμότητας για ερευνητική χρήση.

Η αρχιτεκτονική υλοποιείται σε κατανεμημένο περιβάλλον, με διαχωρισμό μεταξύ υπολογιστικών μονάδων υψηλών απαιτήσεων και υποσυστημάτων χαμηλού επιπέδου ελέγχου.

## 3.2 Συνολική Αρχιτεκτονική Συστήματος

Το σύστημα οργανώνεται σε τρία διακριτά επίπεδα:

1. Επίπεδο Υλικού (Hardware Layer)
Περιλαμβάνει τον ρομποτικό βραχίονα, τους servo motors, τον οδηγό PWM PCA9685, τον Raspberry Pi 4 και τους αισθητήρες (π.χ. depth camera).
2. Επίπεδο Χαμηλού Ελέγχου (Low-Level Control Layer)
Υλοποιείται στον Raspberry Pi 4 και αφορά τη μετατροπή εντολών ελέγχου αρθρώσεων σε φυσική ενεργοποίηση των actuators.
3. Επίπεδο Υψηλού Ελέγχου και Αντίληψης (High-Level Control & Perception Layer)
Εκτελείται στον κεντρικό υπολογιστή (Laptop) και περιλαμβάνει σχεδιασμό κίνησης, αντίληψη περιβάλλοντος, οπτικοποίηση και εκτέλεση εργασιών.

Η επικοινωνία μεταξύ των επιπέδων πραγματοποιείται μέσω του DDS middleware του ROS 2, επιτρέποντας αξιόπιστη και διαφανή ανταλλαγή δεδομένων.

## 3.3 Λειτουργικές Απαιτήσεις Συστήματος

### 3.3.1 FR-1: Περιγραφή και χωρική αναπαράσταση του ρομπότ

Το σύστημα πρέπει να διατηρεί συνεπή γεωμετρική και κινηματική αναπαράσταση του ρομποτικού βραχίονα σε πραγματικό χρόνο.

Η απαίτηση αυτή υλοποιείται μέσω παραμετρικής περιγραφής του ρομπότ σε URDF, με χρήση της γλώσσας Xacro, και μέσω της δημοσίευσης του δέντρου μετασχηματισμών (TF tree). Με τον τρόπο αυτό εξασφαλίζεται κοινό σύστημα αναφοράς για όλα τα υποσυστήματα (σχεδιασμός κίνησης, αντίληψη, οπτικοποίηση).

### 3.3.2 FR-2: Χαμηλού επιπέδου έλεγχος αρθρώσεων

Το σύστημα πρέπει να μεταφράζει εντολές θέσης αρθρώσεων σε πραγματική κίνηση των servo motors με σταθερότητα και χρονική ομαλότητα.

Η απαίτηση αυτή καλύπτεται μέσω του framework ros2_control, το οποίο λειτουργεί ως επίπεδο αφαίρεσης μεταξύ του αλγοριθμικού ελέγχου και του φυσικού hardware.
Ο Raspberry Pi 4 αναλαμβάνει τον ρόλο του hardware interface, οδηγώντας τον PCA9685 για την παραγωγή σταθερού PWM σήματος προς τους servo motors.

### 3.3.3 FR-3: Σχεδιασμός κίνησης με αποφυγή συγκρούσεων

Το σύστημα πρέπει να είναι ικανό να σχεδιάζει τροχιές κίνησης λαμβάνοντας υπόψη κινηματικούς περιορισμούς, όρια αρθρώσεων και πιθανά εμπόδια στο περιβάλλον.

Η απαίτηση αυτή υλοποιείται μέσω του MoveIt 2, το οποίο παρέχει αλγορίθμους σχεδιασμού κίνησης, λύτες κινηματικής και μηχανισμό διαχείρισης σκηνής (planning scene) για έλεγχο συγκρούσεων.

### 3.3.4 FR-4: Αντίληψη περιβάλλοντος (Perception)

Το σύστημα πρέπει να είναι ικανό να αντιλαμβάνεται αντικείμενα στον χώρο εργασίας και να εκτιμά τη χωρική τους θέση.

Η αντίληψη βασίζεται σε δεδομένα RGB-D από αισθητήρα βάθους, τα οποία μετασχηματίζονται στο κοινό σύστημα αναφοράς του ρομπότ. Τα δεδομένα αυτά χρησιμοποιούνται για την εκτίμηση της τρισδιάστατης θέσης και του προσανατολισμού στόχων, επιτρέποντας λειτουργίες vision-based manipulation.

### 3.3.5 FR-5: Εκτέλεση σύνθετων εργασιών (Pick & Place)

Το σύστημα πρέπει να υποστηρίζει την εκτέλεση σύνθετων εργασιών υψηλού επιπέδου, όπως η διαδικασία pick-and-place.

Η λειτουργία αυτή υλοποιείται μέσω task-level κόμβου, ο οποίος οργανώνει τη λογική ακολουθία ενεργειών (προσέγγιση αντικειμένου, σύλληψη, μεταφορά και απόθεση), αξιοποιώντας τις υπηρεσίες σχεδιασμού και εκτέλεσης τροχιών του MoveIt.

### 3.3.6 FR-6: Προσομοίωση και ψηφιακό δίδυμο

Το σύστημα πρέπει να υποστηρίζει πλήρη προσομοίωση της λειτουργίας του χωρίς την ανάγκη φυσικού hardware.

Η απαίτηση αυτή καλύπτεται μέσω της ενσωμάτωσης περιβάλλοντος προσομοίωσης (Gazebo) και προσομοιωμένων controllers του ros2_control, επιτρέποντας την ανάπτυξη και δοκιμή του λογισμικού σε ασφαλές και ελεγχόμενο περιβάλλον.

### 3.3.7 FR-7: Καταγραφή και ανάλυση δεδομένων

Το σύστημα πρέπει να επιτρέπει την καταγραφή και αναπαραγωγή δεδομένων για σκοπούς debugging και ερευνητικής ανάλυσης.

Η λειτουργία αυτή υλοποιείται μέσω του εργαλείου rosbag2, το οποίο επιτρέπει την αποθήκευση δεδομένων αισθητήρων, καταστάσεων αρθρώσεων και τροχιών κίνησης.

## 3.4 Συμπεράσματα Κεφαλαίου

Το παρόν κεφάλαιο παρουσίασε τη λογισμική αρχιτεκτονική του ρομποτικού βραχίονα και τη σύνδεσή της με τις λειτουργικές απαιτήσεις του συστήματος.

Η υιοθετούμενη αρχιτεκτονική εξασφαλίζει υψηλό βαθμό αρθρωτότητας, επεκτασιμότητας και επαναχρησιμοποίησης, καθιστώντας το σύστημα κατάλληλο τόσο για εκπαιδευτική όσο και για ερευνητική χρήση.

### ROS 2 Software Stack – Libraries, Installation & Purpose

### Robot Model & TF

Library / Package | Install Location | Purpose
xacro | Laptop, Raspberry Pi | Parametric URDF description using macros.
robot_state_publisher | Laptop, Raspberry Pi | Publishes TF tree from joint states.
joint_state_publisher_gui | Laptop | GUI tool for manual joint testing.
tf2_ros | Laptop, Raspberry Pi | Coordinate frame transformations.
tf2_tools | Laptop | TF tree debugging tools.

### Low-Level Servo Actuation (PCA9685)

Library / Package | Install Location | Purpose
i2c-tools | Raspberry Pi | Low-level I2C diagnostics and bus scan.
smbus2 | Raspberry Pi | Python interface for I2C communication.
adafruit-blinka | Raspberry Pi | CircuitPython hardware abstraction for Linux SBCs.
adafruit-circuitpython-pca9685 | Raspberry Pi | Stable 12-bit PWM generation for servo motors.
numpy | Raspberry Pi | Math utilities, filtering, angle-to-PWM mapping.
arm_hardware (custom) | Raspberry Pi | ROS 2 node translating joint commands to PWM signals.

### ros2_control & Controllers

Library / Package | Install Location | Purpose
ros2_control | Raspberry Pi | Hardware abstraction and controller lifecycle framework.
ros2_controllers | Raspberry Pi | Standard joint, trajectory and state controllers.
joint_trajectory_controller | Raspberry Pi | Executes smooth joint trajectories.
joint_state_broadcaster | Raspberry Pi | Publishes joint states to

| | ROS graph.
arm_ros2_control (custom) | Raspberry Pi | Hardware interface plugin for PCA9685-based servos.

### Motion Planning (MoveIt 2)

Library / Package | Install Location | Purpose
moveit_ros_move_group | Laptop | Central motion planning and execution node.
moveit_planners | Laptop | Sampling-based planners (OMPL).
moveit_kinematics | Laptop | Forward and inverse kinematics solvers.
moveit_servo | Laptop | Real-time Cartesian control of end-effector.
moveit_task_constructor | Laptop (optional) | High-level composition of manipulation tasks.

### Perception (Vision & Depth)

Library / Package | Install Location | Purpose
Depth camera driver (e.g. realsense2_camera) | Raspberry Pi | RGB-D acquisition and point cloud publishing.
image_transport | Laptop, Raspberry Pi | Efficient transport of image topics.
tf2_sensor_msgs | Laptop, Raspberry Pi | Transform sensor data between coordinate frames.
pcl_ros | Laptop, Raspberry Pi (optional) | Point cloud processing and filtering.
python3-opencv | Laptop, Raspberry Pi | Image processing and feature extraction.
arm_perception (custom) | Laptop / Raspberry Pi | Object detection and 3D pose estimation.

### Simulation & Digital Twin

Library / Package | Install Location | Purpose
gazebo_ros_pkgs / ros_gz_* | Laptop | Physics-based robot simulation.
ros2_control simulation plugins | Laptop | Simulated joint control using same controllers.
MoveIt + RViz (simulation) | Laptop | Planning and visualization without physical hardware.

### Logging & Analysis

Library / Package | Install Location | Purpose
rosbag2 | Laptop, Raspberry Pi (optional) | Record and replay ROS topics.
ROS 2 CLI tools | Laptop, Raspberry Pi | Inspection and debugging of ROS graph.
foxglove_bridge | Laptop, Raspberry Pi | Live telemetry and

(optional) | visualization dashboard.

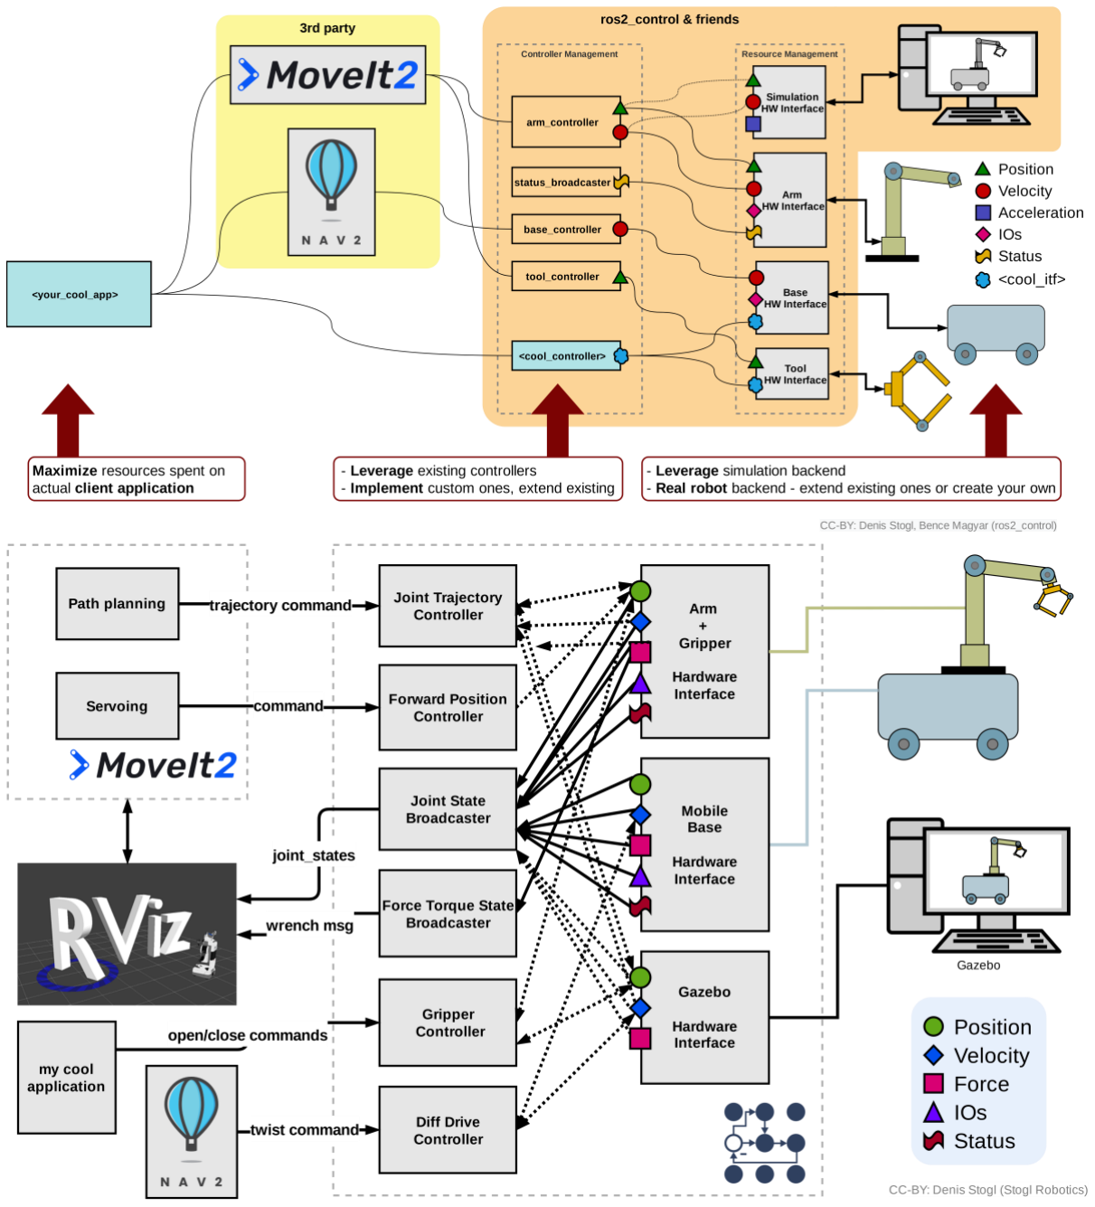
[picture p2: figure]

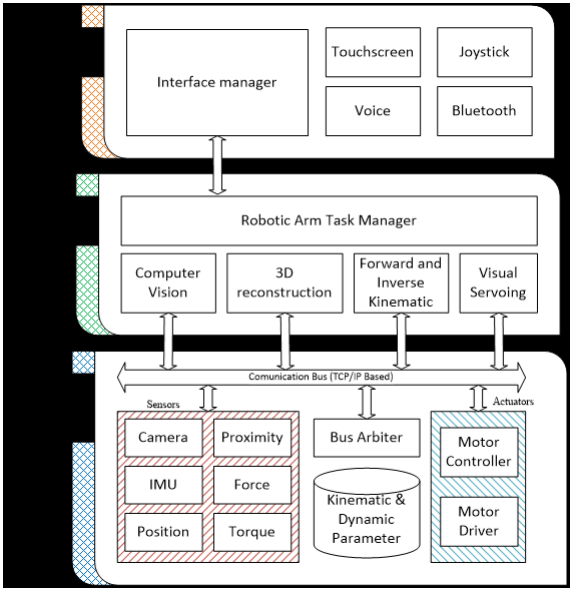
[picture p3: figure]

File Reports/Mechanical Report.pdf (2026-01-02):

# 1. Εισαγωγή και στόχος μηχανολογικού σχεδιασμού

Η παρούσα εργασία πραγματεύεται τη μελέτη, τον σχεδιασμό και την ανάπτυξη ενός αρθρωτού ρομποτικού βραχίονα έξι βαθμών ελευθερίας (6-DOF), με έμφαση στον μηχανολογικό σχεδιασμό και στη μηχανική του συμπεριφορά υπό πραγματικές συνθήκες φόρτισης. Ο ρομποτικός βραχίονας προορίζεται για εφαρμογές γενικής χρήσης, όπως χειρισμό αντικειμένων και πειραματική έρευνα, με στόχο την επίτευξη ικανοποιητικής ακρίβειας, μηχανικής ακαμψίας και λειτουργικής ευελιξίας, διατηρώντας ταυτόχρονα χαμηλό κόστος κατασκευής.

Βασική σχεδιαστική απαίτηση του συστήματος αποτελεί η δυνατότητα χειρισμού ωφέλιμου φορτίου (payload) έως 2 kg στο άκρο του βραχίονα, σε πλήρη χωρική κίνηση. Η απαίτηση αυτή επηρεάζει άμεσα τον μηχανολογικό σχεδιασμό, καθώς καθορίζει τα αναπτυσσόμενα φορτία και ροπές στους συνδέσμους και στις αρθρώσεις του μηχανισμού, καθώς και τις απαιτήσεις αντοχής και ακαμψίας των επιμέρους δομικών στοιχείων.

Η φιλοσοφία σχεδίασης του ρομποτικού βραχίονα βασίζεται στις αρχές της αρθρωτής (modular) μηχανικής αρχιτεκτονικής και της κατασκευής μέσω προσθετικών μεθόδων (3D printing). Κάθε βασικό δομικό τμήμα του βραχίονα σχεδιάζεται ως ανεξάρτητο μηχανικό module, το οποίο περιλαμβάνει το φέρον σώμα, τα στοιχεία έδρασης, τα σημεία σύνδεσης με τους γειτονικούς συνδέσμους και τη μηχανική διεπαφή με το σύστημα κίνησης. Η προσέγγιση αυτή επιτρέπει την ευκολότερη επανασχεδίαση, αντικατάσταση ή βελτιστοποίηση επιμέρους τμημάτων χωρίς την ανάγκη ανακατασκευής του συνόλου του μηχανισμού.

Ιδιαίτερη έμφαση δίνεται στη χρήση υλικών κατάλληλων για τρισδιάστατη εκτύπωση, όπως πολυμερή θερμοπλαστικά (π.χ. PLA+, ABS και ενισχυμένα σύνθετα υλικά), τα οποία επιλέγονται με βάση τις μηχανικές απαιτήσεις κάθε εξαρτήματος. Η επιλογή των υλικών δεν γίνεται ενιαία για όλα τα μέρη, αλλά διαφοροποιείται ανάλογα με το επίπεδο καταπόνησης, τη γεωμετρία και τον λειτουργικό ρόλο κάθε συνδέσμου. Με τον τρόπο αυτό επιτυγχάνεται βέλτιστος συνδυασμός μηχανικής αντοχής, βάρους και ευκολίας κατασκευής.

Ο μηχανολογικός σχεδιασμός του ρομποτικού βραχίονα δεν περιορίζεται στη γεωμετρική διαμόρφωση των επιμέρους εξαρτημάτων, αλλά ενσωματώνει στοιχεία μηχανικής ανάλυσης και βελτιστοποίησης. Συγκεκριμένα, λαμβάνονται υπόψη οι αναπτυσσόμενες ροπές στις αρθρώσεις, τα σενάρια μέγιστης φόρτισης (worst-case loading conditions), καθώς και η κατανομή των τάσεων στο εσωτερικό των δομικών στοιχείων. Στο πλαίσιο αυτό, αξιοποιούνται τεχνικές γενετικού σχεδιασμού (generative design), οι οποίες επιτρέπουν την παραγωγή ελαφριών αλλά μηχανικά αποδοτικών γεωμετριών, προσαρμοσμένων στις συγκεκριμένες συνθήκες φόρτισης και στους κατασκευαστικούς περιορισμούς.

Η μηχανολογική μελέτη του βραχίονα αποτελεί θεμελιώδη συνιστώσα του συνολικού συστήματος και επηρεάζει άμεσα τόσο τον ηλεκτρολογικό όσο και τον λογισμικό σχεδιασμό. Η ακαμψία της δομής, η ακρίβεια των αρθρώσεων και η μηχανική συμπεριφορά υπό δυναμική φόρτιση καθορίζουν τις απαιτήσεις του συστήματος ελέγχου, την επιλογή των ενεργοποιητών και την επίδοση των αλγορίθμων κίνησης. Κατά συνέπεια, ο μηχανολογικός σχεδιασμός αντιμετωπίζεται ως η βάση πάνω στην οποία δομούνται όλα τα υπόλοιπα υποσυστήματα του ρομποτικού βραχίονα.

Στο παρόν κεφάλαιο παρουσιάζεται αναλυτικά η μηχανολογική ανάπτυξη του ρομποτικού βραχίονα, ξεκινώντας από την αρχιτεκτονική των βαθμών ελευθερίας και την αρθρωτή δομή του συστήματος, συνεχίζοντας με τη διαδικασία σχεδίασης των μηχανικών μερών, την επιλογή υλικών και τη μελέτη των συστημάτων μετάδοσης κίνησης, και καταλήγοντας στην ανάλυση φορτίων, την αξιολόγηση της μηχανικής αντοχής και την κατασκευαστική διαδικασία μέσω τρισδιάστατης εκτύπωσης.

## 2. Αρχιτεκτονική ρομποτικού βραχίονα

### 2.1 Διάταξη βαθμών ελευθερίας (6-DOF)

Ο ρομποτικός βραχίονας που αναπτύσσεται στην παρούσα εργασία διαθέτει έξι βαθμούς ελευθερίας (6 Degrees of Freedom – 6 DOF), επιτρέποντας την πλήρη χωρική τοποθέτηση και προσανατολισμό του τελικού ενεργοποιητή (end-effector) εντός του τρισδιάστατου χώρου. Η επιλογή διάταξης 6-DOF αποτελεί καθιερωμένη πρακτική σε βιομηχανικούς και ερευνητικούς ρομποτικούς βραχίονες, καθώς εξασφαλίζει ανεξάρτητο έλεγχο τόσο της θέσης όσο και του προσανατολισμού του άκρου εργασίας.

Η αρχιτεκτονική του συστήματος ακολουθεί σειριακή διάταξη αρθρώσεων, όπου κάθε βαθμός ελευθερίας αντιστοιχεί σε μία περιστροφική άρθρωση. Η συνολική διάταξη των βαθμών ελευθερίας μπορεί να διακριθεί λειτουργικά σε τρία κύρια τμήματα: τη βάση, τον κύριο βραχίονα (arm) και τον καρπό (wrist).

Ο πρώτος βαθμός ελευθερίας αφορά την περιστροφή της βάσης γύρω από κατακόρυφο άξονα. Η άρθρωση αυτή επιτρέπει την οριζόντια σάρωση του χώρου εργασίας και καθορίζει σε μεγάλο βαθμό το συνολικό εύρος λειτουργίας του βραχίονα. Η μηχανολογική σχεδίαση της βάσης οφείλει να εξασφαλίζει αυξημένη ακαμψία, καθώς η συγκεκριμένη άρθρωση φέρει το βάρος όλων των υπερκείμενων συνδέσμων και του ωφέλιμου φορτίου.

Ο δεύτερος και ο τρίτος βαθμός ελευθερίας αντιστοιχούν στις αρθρώσεις του ώμου και του αγκώνα αντίστοιχα. Οι δύο αυτές αρθρώσεις αποτελούν τον κύριο μηχανισμό τοποθέτησης του άκρου του βραχίονα στον χώρο και είναι υπεύθυνες για τη ρύθμιση της απόστασης και του ύψους του end-effector σε σχέση με τη βάση. Οι αναπτυσσόμενες ροπές στις συγκεκριμένες αρθρώσεις είναι ιδιαίτερα αυξημένες, ειδικά υπό συνθήκες μέγιστης έκτασης του βραχίονα και πλήρους ωφέλιμου φορτίου. Ως εκ τούτου, η γεωμετρία, η επιλογή υλικών και η διάταξη των μηχανικών στοιχείων των αρθρώσεων αυτών αποτελούν κρίσιμα σημεία του μηχανολογικού σχεδιασμού.

Οι τρεις τελευταίοι βαθμοί ελευθερίας συνθέτουν τον καρπό του ρομποτικού βραχίονα, επιτρέποντας την ανεξάρτητη ρύθμιση του προσανατολισμού του end-effector. Η διάταξη αυτή συνήθως υλοποιείται μέσω διαδοχικών περιστροφικών αρθρώσεων, οι οποίες αντιστοιχούν σε κινήσεις τύπου roll, pitch και yaw. Ο ρόλος του καρπού είναι καθοριστικός για εφαρμογές χειρισμού αντικειμένων, καθώς επιτρέπει την προσαρμογή της στάσης του εργαλείου ή της δαγκάνας χωρίς μεταβολή της θέσης του άκρου στον χώρο.

Η επιλογή σειριακής αρχιτεκτονικής 6-DOF συνεπάγεται αυξημένες μηχανικές απαιτήσεις, καθώς τα φορτία και οι ροπές μεταφέρονται αθροιστικά από τον τελικό ενεργοποιητή προς τη βάση. Παρά το μειονέκτημα αυτό, η συγκεκριμένη αρχιτεκτονική προσφέρει σημαντικά πλεονεκτήματα όσον αφορά την απλότητα του μηχανικού σχεδιασμού, τη δυνατότητα αρθρωτής κατασκευής και τη συμβατότητα με καθιερωμένες μεθόδους κινηματικής και ελέγχου.

Στο Σχήμα 2.1 παρουσιάζεται το πλήρες μηχανολογικό μοντέλο του ρομποτικού βραχίονα, στο οποίο επισημαίνονται οι έξι βαθμοί ελευθερίας και η αντίστοιχη άρθρωση κάθε άξονα κίνησης. Η διάταξη αυτή αποτελεί τη βάση πάνω στην οποία αναπτύσσεται η υπόλοιπη μηχανολογική σχεδίαση, συμπεριλαμβανομένης της ανάλυσης φορτίων, της βελτιστοποίησης των δομικών στοιχείων και της κατασκευαστικής διαδικασίας.

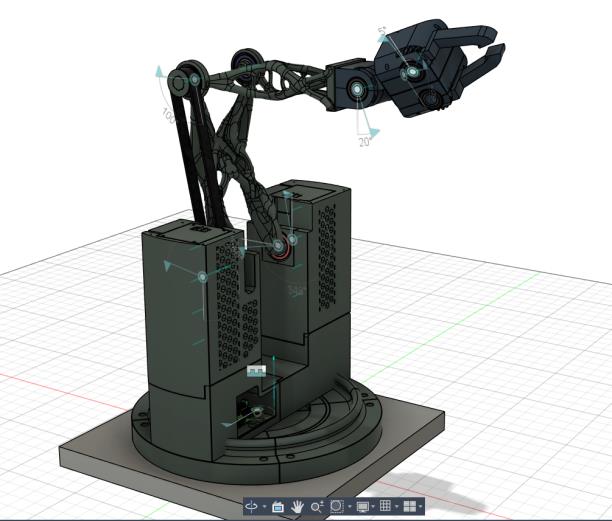
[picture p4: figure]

### 2.2 Modular σχεδίαση μηχανικής δομής (αρθρωτά υποσυστήματα –

“Bones”)

Η μηχανολογική αρχιτεκτονική του ρομποτικού βραχίονα βασίζεται στην αρχή της αρθρωτής (modular) σχεδίασης, σύμφωνα με την οποία το σύστημα διαχωρίζεται σε επιμέρους μηχανικά υποσυστήματα, τα οποία σχεδιάζονται, αναλύονται και βελτιστοποιούνται σε μεγάλο βαθμό ανεξάρτητα. Στο πλαίσιο της παρούσας εργασίας, τα υποσυστήματα αυτά αναφέρονται ως Bones και αντιστοιχούν στους βασικούς φέροντες συνδέσμους και στις αρθρώσεις του βραχίονα.

Κάθε Bone αποτελεί ένα ολοκληρωμένο μηχανολογικό module, το οποίο περιλαμβάνει:

- το φέρον δομικό σώμα,
- τις επιφάνειες σύνδεσης με γειτονικούς συνδέσμους,
- τις έδρες για την ενσωμάτωση εδράνων ή αξόνων περιστροφής,
- καθώς και τη μηχανική διεπαφή με το σύστημα μετάδοσης κίνησης και τον ενεργοποιητή.

Η προσέγγιση αυτή επιτρέπει την αποσύνδεση του συνολικού μηχανικού προβλήματος σε επιμέρους υποπροβλήματα μικρότερης κλίμακας. Με τον τρόπο αυτό, η ανάλυση φορτίων, η επιλογή υλικών και η γεωμετρική βελτιστοποίηση μπορούν να πραγματοποιηθούν ξεχωριστά για κάθε Bone, λαμβάνοντας υπόψη τις ειδικές συνθήκες καταπόνησης που επικρατούν στη συγκεκριμένη θέση του βραχίονα.

Από μηχανολογικής άποψης, τα Bones που βρίσκονται εγγύτερα στη βάση του βραχίονα υπόκεινται σε σημαντικά αυξημένες ροπές και διατμητικές δυνάμεις, καθώς καλούνται να φέρουν όχι μόνο το ωφέλιμο φορτίο των 2 kg, αλλά και το βάρος όλων των υπερκείμενων συνδέσμων και αρθρώσεων. Αντιθέτως, τα Bones που απαρτίζουν τον καρπό και το άκρο του βραχίονα υπόκεινται σε μικρότερες ροπές, αλλά απαιτούν αυξημένη ακρίβεια και μειωμένη παραμόρφωση, προκειμένου να διασφαλιστεί ο σωστός προσανατολισμός του end-effector.

Η αρθρωτή σχεδίαση επιτρέπει την προσαρμογή της γεωμετρίας και της εσωτερικής δομής κάθε Bone στις τοπικές μηχανικές απαιτήσεις. Για παράδειγμα, σε συνδέσμους υψηλής καταπόνησης δίνεται προτεραιότητα στην αύξηση της ακαμψίας και στη βέλτιστη κατανομή των τάσεων, ακόμη και εις βάρος της αύξησης της μάζας. Αντιθέτως, σε συνδέσμους χαμηλότερης φόρτισης, ο σχεδιασμός εστιάζει στη μείωση του βάρους και της ροπής αδράνειας, προκειμένου να βελτιωθεί η δυναμική απόκριση του συστήματος.

Ένα ακόμη κρίσιμο πλεονέκτημα της modular προσέγγισης είναι η ευκολία επανασχεδίασης και εξέλιξης του μηχανισμού. Τυχόν αστοχίες, ανεπιθύμητες παραμορφώσεις ή περιορισμοί στην απόδοση μπορούν να αντιμετωπιστούν με την τροποποίηση ενός συγκεκριμένου Bone, χωρίς να απαιτείται συνολική ανακατασκευή του βραχίονα. Η δυνατότητα αυτή είναι ιδιαίτερα σημαντική στο πλαίσιο ερευνητικών και εκπαιδευτικών εφαρμογών, όπου η επαναληπτική διαδικασία σχεδίασης–δοκιμής– βελτιστοποίησης αποτελεί βασικό στοιχείο της ανάπτυξης.

Η modular σχεδίαση συνδέεται άμεσα και με την επιλογή της προσθετικής κατασκευής μέσω τρισδιάστατης εκτύπωσης. Κάθε Bone μπορεί να κατασκευαστεί ανεξάρτητα, με προσαρμοσμένες παραμέτρους εκτύπωσης, υλικά και προσανατολισμό, ανάλογα με τη γεωμετρία και τις μηχανικές απαιτήσεις του. Παράλληλα, η ύπαρξη σαφώς ορισμένων διεπαφών μεταξύ των Bones διευκολύνει τη συναρμολόγηση, την αποσυναρμολόγηση και τη μελλοντική αντικατάσταση επιμέρους εξαρτημάτων.

Συνολικά, η επιλογή αρθρωτής μηχανολογικής αρχιτεκτονικής αποτελεί βασικό σχεδιαστικό άξονα της παρούσας εργασίας και συνεισφέρει καθοριστικά στη λειτουργικότητα, την ευελιξία και τη μελλοντική επεκτασιμότητα του ρομποτικού βραχίονα. Η προσέγγιση αυτή δημιουργεί ένα σταθερό μηχανολογικό υπόβαθρο, πάνω στο οποίο μπορούν να αναπτυχθούν και να ενσωματωθούν αποτελεσματικά τα ηλεκτρολογικά και λογισμικά υποσυστήματα του συστήματος.

## 3. Σχεδίαση μηχανικών μερών

### 3.1 CAD περιβάλλον και σχεδιαστική διαδικασία

Η σχεδίαση των μηχανικών μερών του ρομποτικού βραχίονα πραγματοποιήθηκε σε ολοκληρωμένο τρισδιάστατο περιβάλλον CAD, το οποίο επιτρέπει τη δημιουργία παραμετρικών μοντέλων, τη συναρμολόγηση πολύπλοκων μηχανισμών και την ενσωμάτωση εργαλείων ανάλυσης και βελτιστοποίησης. Η επιλογή παραμετρικής σχεδίασης κρίθηκε απαραίτητη, καθώς επιτρέπει την εύκολη τροποποίηση γεωμετρικών χαρακτηριστικών (μήκη, πάχη, θέσεις αξόνων) σε μεταγενέστερα στάδια της ανάπτυξης, χωρίς την ανάγκη εκ νέου μοντελοποίησης από την αρχή.

Η σχεδιαστική διαδικασία ακολούθησε επαναληπτική (iterative) μεθοδολογία, η οποία μπορεί να συνοψιστεί στα ακόλουθα βασικά στάδια:

1. Αρχική γεωμετρική σύλληψη (conceptual design)
Σε αυτό το στάδιο καθορίστηκε η βασική γεωμετρία κάθε συνδέσμου, τα σημεία άρθρωσης και οι διεπαφές σύνδεσης μεταξύ των επιμέρους Bones. Η γεωμετρία σχεδιάστηκε αρχικά με απλοποιημένες μορφές, με στόχο την κατανόηση της κινηματικής συμπεριφοράς και της συνολικής διάταξης του μηχανισμού.
2. Συναρμολόγηση και έλεγχος κινηματικής
Τα επιμέρους εξαρτήματα ενσωματώθηκαν σε πλήρες assembly του ρομποτικού βραχίονα, όπου ελέγχθηκε η σωστή λειτουργία των αρθρώσεων, τα επιτρεπτά εύρη κίνησης και η απουσία μηχανικών παρεμβολών (collisions). Το στάδιο αυτό είναι κρίσιμο, καθώς επιτρέπει την έγκαιρη αναγνώριση γεωμετρικών αστοχιών πριν την περαιτέρω ανάλυση.
3. Προσαρμογή γεωμετρίας βάσει μηχανικών απαιτήσεων
Με βάση τις εκτιμώμενες ροπές και φορτίσεις σε κάθε άρθρωση, πραγματοποιήθηκαν τροποποιήσεις στη γεωμετρία των φερόντων μερών, όπως αύξηση τοπικών πάχους, ενίσχυση περιοχών σύνδεσης και βελτίωση της κατανομής υλικού σε κρίσιμα σημεία.
4. Προετοιμασία για ανάλυση και βελτιστοποίηση
Στο τελικό στάδιο της σχεδίασης CAD, τα μοντέλα προσαρμόστηκαν ώστε να είναι κατάλληλα για περαιτέρω ανάλυση, όπως δομικό έλεγχο ή εφαρμογή γενετικού σχεδιασμού. Σε αυτό περιλαμβάνεται ο σαφής ορισμός περιοχών που πρέπει να διατηρηθούν (preserve regions) και περιοχών που μπορούν να βελτιστοποιηθούν γεωμετρικά.

Στο Σχήμα 3.1 παρουσιάζεται το πλήρες συναρμολογημένο CAD μοντέλο του ρομποτικού βραχίονα, το οποίο αποτελεί τη βάση για όλες τις επόμενες μηχανολογικές αναλύσεις.

(Σχήμα 3.1: Πλήρες CAD assembly του ρομποτικού βραχίονα.)

### 3.2 Εφαρμογή γενετικού σχεδιασμού (Generative Design) και δομική

βελτιστοποίηση

Για τη βελτίωση της μηχανικής απόδοσης των φερόντων συνδέσμων του ρομποτικού βραχίονα εφαρμόστηκαν τεχνικές γενετικού σχεδιασμού (generative design), με στόχο την επίτευξη βέλτιστου συνδυασμού ακαμψίας και μειωμένης μάζας. Η χρήση γενετικού σχεδιασμού κρίνεται ιδιαίτερα κατάλληλη σε περιπτώσεις όπου τα φορτία είναι γνωστά, αλλά η βέλτιστη γεωμετρία δεν είναι προφανής μέσω κλασικών σχεδιαστικών προσεγγίσεων.

Η διαδικασία γενετικού σχεδιασμού βασίζεται στον ορισμό ενός σαφούς σχεδιαστικού προβλήματος, το οποίο περιλαμβάνει:

- τις περιοχές γεωμετρίας που πρέπει να διατηρηθούν (preserve geometry),
- τις περιοχές που απαγορεύεται να καταληφθούν από υλικό (obstacle geometry),
- τις συνθήκες στήριξης και φόρτισης,
- καθώς και τους στόχους βελτιστοποίησης, όπως η ελαχιστοποίηση της μάζας ή της παραμόρφωσης.

Στην παρούσα εργασία, ο γενετικός σχεδιασμός εφαρμόστηκε κυρίως σε Bones υψηλής μηχανικής καταπόνησης, όπως συνδέσμους του κύριου βραχίονα, όπου οι αναπτυσσόμενες ροπές λόγω του ωφέλιμου φορτίου των 2 kg είναι σημαντικές. Ως αρχική γεωμετρία (starting shape) χρησιμοποιήθηκε απλοποιημένο φέρον σώμα, το οποίο περιέκλειε τον διαθέσιμο χώρο σχεδίασης και εξασφάλιζε τη σωστή σύνδεση με τα γειτονικά εξαρτήματα.

Οι συνθήκες φόρτισης ορίστηκαν με βάση σενάρια μέγιστης καταπόνησης, λαμβάνοντας υπόψη τη δυσμενέστερη θέση του βραχίονα (πλήρης εκτατότητα) και την εφαρμογή του ωφέλιμου φορτίου στο άκρο. Οι στηρίξεις προσομοιώθηκαν μέσω κατάλληλων περιορισμών στις επιφάνειες σύνδεσης των αρθρώσεων, ώστε να αναπαριστούν ρεαλιστικά τη μηχανική συμπεριφορά του συστήματος.

Στο Σχήμα 3.2 παρουσιάζεται ενδεικτικά η διαμόρφωση του σχεδιαστικού χώρου, των περιοχών διατήρησης γεωμετρίας και των εφαρμοζόμενων φορτίων για έναν από τους βασικούς συνδέσμους του βραχίονα.

Bone1.

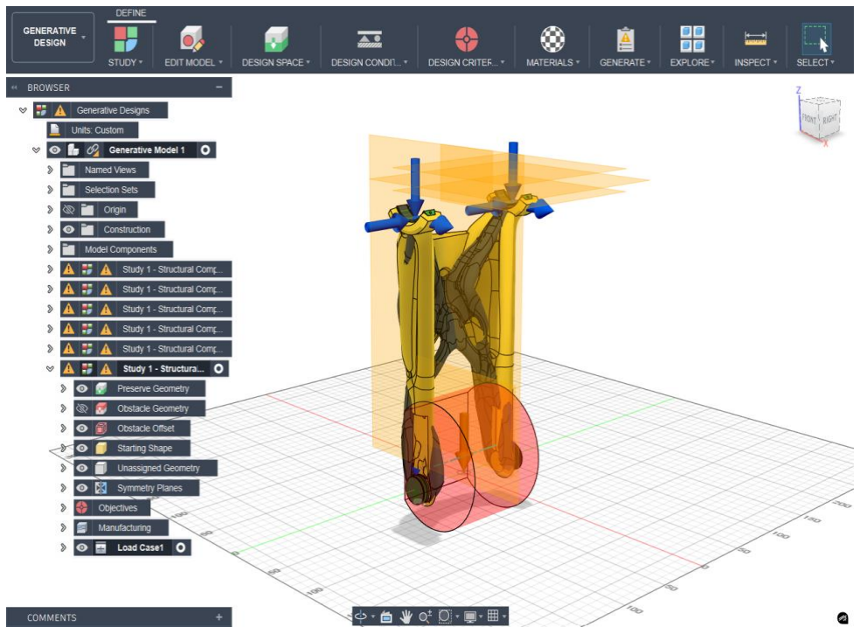
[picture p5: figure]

Bone 2.

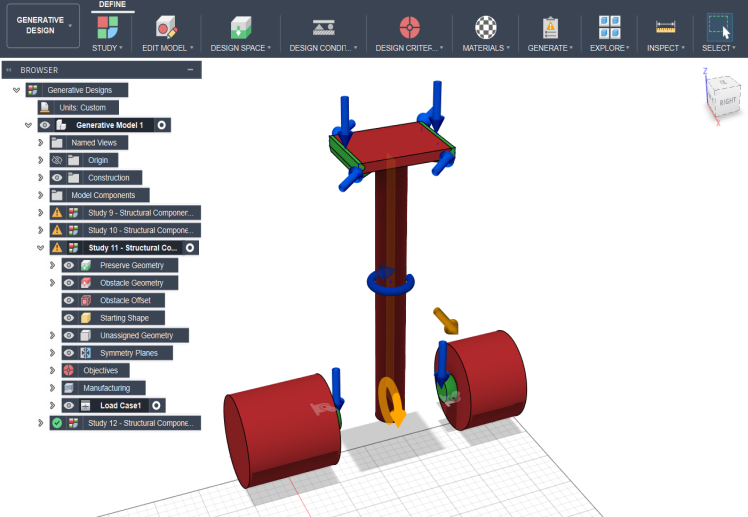
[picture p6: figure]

(Σχήμα 3.2: Ορισμός σχεδιαστικού χώρου, περιοχών διατήρησης και φορτίσεων για εφαρμογή γενετικού σχεδιασμού.)

Τα αποτελέσματα του γενετικού σχεδιασμού περιλαμβάνουν πολλαπλές εναλλακτικές γεωμετρίες, οι οποίες ικανοποιούν τους ίδιους μηχανικούς περιορισμούς αλλά παρουσιάζουν διαφορετική κατανομή υλικού και συνολική μάζα. Οι προτεινόμενες λύσεις συγκρίθηκαν με βάση κριτήρια όπως η μηχανική ακαμψία, η ευκολία κατασκευής μέσω τρισδιάστατης εκτύπωσης και η συμβατότητα με τη συνολική αρχιτεκτονική του βραχίονα.

Στο Σχήμα 3.3 παρουσιάζονται χαρακτηριστικά αποτελέσματα γενετικού σχεδιασμού για επιλεγμένο Bone, όπου διακρίνεται η οργανική κατανομή του υλικού σε περιοχές υψηλής καταπόνησης και η αφαίρεσή του από περιοχές μειωμένης μηχανικής σημασίας.

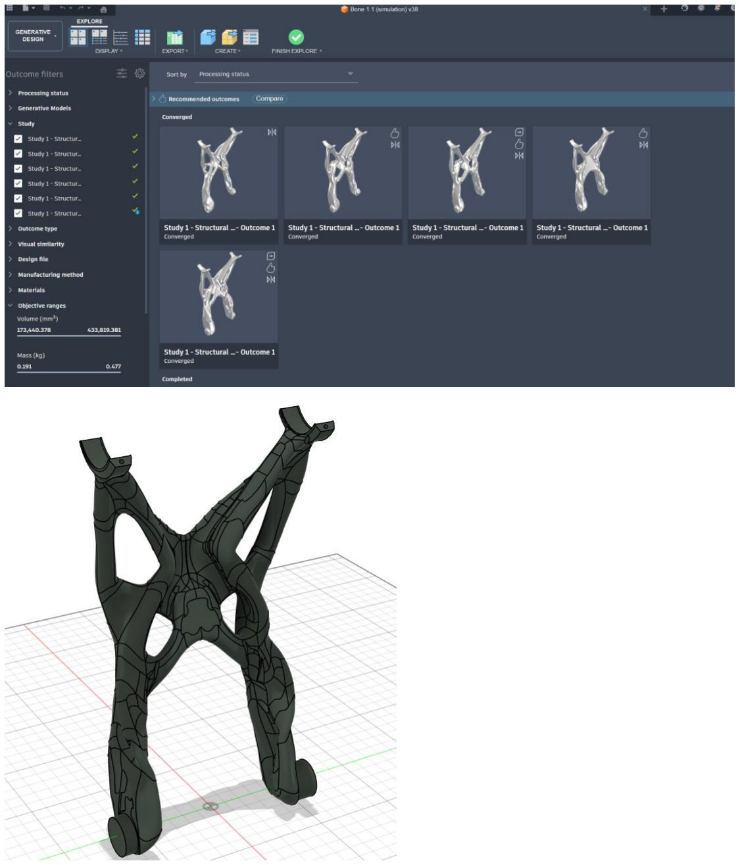
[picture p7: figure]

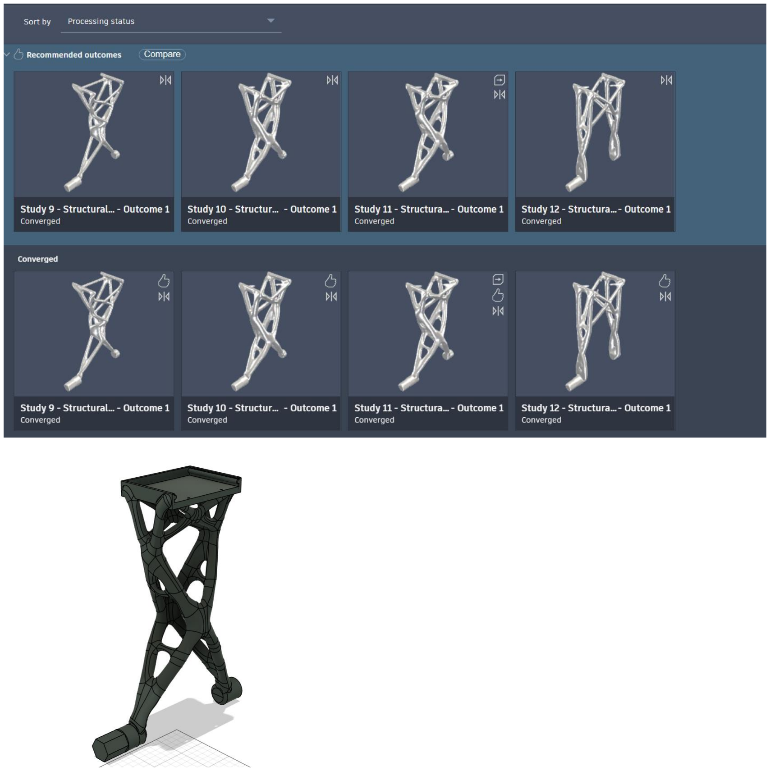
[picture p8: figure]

(Σχήμα 3.3: Ενδεικτικά αποτελέσματα γενετικού σχεδιασμού για φέρον σύνδεσμο του ρομποτικού βραχίονα.)

Η τελική γεωμετρία που επελέγη δεν αποτελεί άμεση εξαγωγή ενός αποτελέσματος γενετικού σχεδιασμού, αλλά προϊόν μηχανολογικής κρίσης και περαιτέρω επεξεργασίας, ώστε να ικανοποιεί τόσο τις μηχανικές απαιτήσεις όσο και τους κατασκευαστικούς περιορισμούς της προσθετικής κατασκευής. Με τον τρόπο αυτό, ο γενετικός σχεδιασμός αξιοποιήθηκε ως εργαλείο υποστήριξης της σχεδιαστικής διαδικασίας και όχι ως αυτόματη αντικατάστασή της.

## 4. Ανάλυση φορτίων και μηχανικών καταπονήσεων

### 4.1 Ανάλυση φορτίων και ροπών (payload 2 kg)

Η ανάλυση φορτίων και ροπών αποτελεί κρίσιμο στάδιο του μηχανολογικού σχεδιασμού του ρομποτικού βραχίονα, καθώς καθορίζει τις απαιτήσεις αντοχής, ακαμψίας και διαστασιολόγησης των φερόντων συνδέσμων και των αρθρώσεων. Στην παρούσα εργασία, η ανάλυση πραγματοποιείται με βάση συντηρητικά σενάρια μέγιστης καταπόνησης (worst-case loading conditions), ώστε να διασφαλίζεται η ασφαλής λειτουργία του συστήματος υπό όλες τις προβλεπόμενες συνθήκες.

### 4.1.1 Υποθέσεις και παραδοχές ανάλυσης

Για την πραγματοποίηση της ανάλυσης υιοθετούνται οι ακόλουθες παραδοχές:

- Το ωφέλιμο φορτίο (payload) στο άκρο του βραχίονα ισούται με

mp=2 kgm_p = 2~\text{kg}mp =2 kg

- Η επιτάχυνση της βαρύτητας λαμβάνεται ίση με

g=9.81 m/s2g = 9.81~\text{m/s}^2g=9.81 m/s2

- Οι σύνδεσμοι του βραχίονα θεωρούνται άκαμπτοι σε πρώτο επίπεδο ανάλυσης.
- Η ανάλυση πραγματοποιείται αρχικά σε στατική μορφή, αγνοώντας δυναμικά φαινόμενα (επιταχύνσεις, ταλαντώσεις), τα οποία εξετάζονται σε επόμενο στάδιο σχεδιασμού.
- Η δυσμενέστερη θέση του βραχίονα θεωρείται εκείνη της πλήρους εκτατότητας, όπου οι σύνδεσμοι βρίσκονται σε ευθυγραμμισμένη διάταξη και οι ροπές στις αρθρώσεις μεγιστοποιούνται.

### 4.1.2 Υπολογισμός εφαρμοζόμενης δύναμης στο άκρο

Η δύναμη που ασκείται στο άκρο του βραχίονα λόγω του ωφέλιμου φορτίου δίνεται από τη σχέση:

Fp=mp⋅gF_p = m_p \cdot gFp =mp ⋅g

και αριθμητικά:

Fp=2⋅9.81=19.62 NF_p = 2 \cdot 9.81 = 19.62~\text{N}Fp =2⋅9.81=19.62 N

Η δύναμη αυτή θεωρείται ότι εφαρμόζεται κατακόρυφα προς τα κάτω στο σημείο σύνδεσης του end-effector με τον τελευταίο σύνδεσμο του βραχίονα.

### 4.1.3 Υπολογισμός ροπών στις αρθρώσεις

Έστω ότι ο ρομποτικός βραχίονας αποτελείται από nnn σειριακά συνδεδεμένους συνδέσμους με μήκη L1,L2,…,LnL_1, L_2, \ldots, L_nL1 ,L2 ,…,Ln . Στην περίπτωση πλήρους εκτατότητας, η ροπή που αναπτύσσεται στην άρθρωση iii λόγω του ωφέλιμου φορτίου προσεγγίζεται από τη σχέση:

Mi=Fp⋅∑k=inLkM_i = F_p \cdot \sum_{k=i}^{n} L_kMi =Fp ⋅k=i∑n Lk

Η παραπάνω σχέση εκφράζει το γεγονός ότι κάθε άρθρωση καλείται να φέρει τη ροπή που προκαλείται από το φορτίο σε απόσταση ίση με το άθροισμα των μηκών όλων των υπερκείμενων συνδέσμων.

Για παράδειγμα, στην άρθρωση του ώμου (δεύτερος βαθμός ελευθερίας), η αναπτυσσόμενη ροπή είναι:

Mshoulder=Fp⋅(L2+L3+…+Ln)M_{\text{shoulder}} = F_p \cdot (L_2 + L_3 + \ldots +
L_n)Mshoulder =Fp ⋅(L2 +L3 +…+Ln )

Αντίστοιχα, στην άρθρωση της βάσης (πρώτος βαθμός ελευθερίας), η ροπή μεγιστοποιείται και δίνεται από:

Mbase=Fp⋅(L1+L2+…+Ln)M_{\text{base}} = F_p \cdot (L_1 + L_2 + \ldots + L_n)Mbase
=Fp ⋅(L1 +L2 +…+Ln )

Η παραπάνω ανάλυση καταδεικνύει ότι οι αρθρώσεις που βρίσκονται πλησιέστερα στη βάση υπόκεινται σε σημαντικά αυξημένες ροπές σε σύγκριση με εκείνες του καρπού, γεγονός που δικαιολογεί την ανάγκη για αυξημένη ακαμψία και μηχανική ενίσχυση των αντίστοιχων Bones.

### 4.1.4 Συνεισφορά ιδιοβάρους των συνδέσμων

Πέραν του ωφέλιμου φορτίου, στις αρθρώσεις του βραχίονα συνεισφέρει και το ιδιοβάρος των συνδέσμων. Έστω ότι ο σύνδεσμος jjj έχει μάζα mjm_jmj και το κέντρο μάζας του βρίσκεται σε απόσταση djd_jdj από την άρθρωση iii. Η πρόσθετη ροπή λόγω ιδιοβάρους δίνεται από:

Mi,j=mj⋅g⋅djM_{i,j} = m_j \cdot g \cdot d_jMi,j =mj ⋅g⋅dj

Η συνολική ροπή στην άρθρωση iii προκύπτει ως άθροισμα:

Mitotal=Fp⋅∑k=inLk+∑j=inmj⋅g⋅djM_i^{\text{total}} = F_p \cdot \sum_{k=i}^{n} L_k + \sum_{j=i}^{n} m_j \cdot g \cdot d_jMitotal =Fp ⋅k=i∑n Lk +j=i∑n mj ⋅g⋅dj

Η συνεισφορά του ιδιοβάρους καθίσταται ιδιαίτερα σημαντική σε συνδέσμους μεγάλου μήκους ή αυξημένης μάζας, γεγονός που επηρεάζει άμεσα τις σχεδιαστικές αποφάσεις σχετικά με τη μείωση του βάρους μέσω γεωμετρικής βελτιστοποίησης και γενετικού σχεδιασμού.

### 4.1.5 Worst-case σενάρια καταπόνησης

Για λόγους ασφαλούς διαστασιολόγησης, εξετάζονται τα ακόλουθα worst-case σενάρια:

- πλήρης εκτατότητα του βραχίονα σε οριζόντια διάταξη,
- εφαρμογή του μέγιστου ωφέλιμου φορτίου,
- στατική καταπόνηση χωρίς υποβοήθηση από δυναμικά φαινόμενα (π.χ. επιταχύνσεις προς αντίθετη κατεύθυνση).

Τα σενάρια αυτά οδηγούν σε μεγιστοποίηση των ροπών κάμψης στους φέροντες συνδέσμους και στις αρθρώσεις, και χρησιμοποιούνται ως βάση για τη διαστασιολόγηση των μηχανικών μερών και την εφαρμογή δομικής ανάλυσης στα επόμενα στάδια της μελέτης.

### 4.1.6 Σχέση ανάλυσης φορτίων με τον μηχανολογικό σχεδιασμό

Τα αποτελέσματα της ανάλυσης φορτίων και ροπών αξιοποιούνται άμεσα στον μηχανολογικό σχεδιασμό του ρομποτικού βραχίονα, καθώς:

- καθορίζουν τις περιοχές αυξημένης μηχανικής καταπόνησης,
- ορίζουν τις απαιτήσεις αντοχής των φερόντων Bones,
- και αποτελούν είσοδο για την εφαρμογή γενετικού σχεδιασμού και δομικής βελτιστοποίησης.

Με τον τρόπο αυτό, η ανάλυση φορτίων λειτουργεί ως σύνδεσμος μεταξύ της θεωρητικής μηχανικής θεμελίωσης και της πρακτικής υλοποίησης του μηχανολογικού σχεδιασμού.

## 5. Κατασκευαστική διαδικασία μέσω προσθετικής κατασκευής (3D Printing)

### 5.1 Επιλογή μεθόδου κατασκευής και αιτιολόγηση

Η κατασκευή των μηχανικών μερών του ρομποτικού βραχίονα πραγματοποιήθηκε μέσω προσθετικής κατασκευής (Additive Manufacturing) και συγκεκριμένα με τη μέθοδο της τρισδιάστατης εκτύπωσης θερμοπλαστικών υλικών (Fused Filament Fabrication – FFF). Η επιλογή της συγκεκριμένης μεθόδου υπαγορεύτηκε από το χαμηλό κόστος, την ταχεία παραγωγή πρωτοτύπων και τη δυνατότητα άμεσης επανασχεδίασης και επανεκτύπωσης επιμέρους εξαρτημάτων.

Η προσθετική κατασκευή ευθυγραμμίζεται άμεσα με τη φιλοσοφία της αρθρωτής σχεδίασης που υιοθετήθηκε στον μηχανολογικό σχεδιασμό του βραχίονα. Κάθε Bone μπορεί να κατασκευαστεί ανεξάρτητα, επιτρέποντας τη σταδιακή βελτίωση της γεωμετρίας και την αξιολόγηση διαφορετικών σχεδιαστικών επιλογών χωρίς σημαντικό κατασκευαστικό κόστος.

### 5.2 Παράμετροι εκτύπωσης και σχεδιαστικές προσαρμογές

Κατά τη διαδικασία εκτύπωσης, οι παράμετροι επιλέχθηκαν με βάση τις μηχανικές απαιτήσεις κάθε εξαρτήματος και τη θέση του στον βραχίονα. Ειδικότερα, ελήφθησαν υπόψη:

- το ποσοστό πλήρωσης (infill), το οποίο αυξήθηκε σε φέροντα μέρη υψηλής καταπόνησης,
- το πάχος τοιχωμάτων (perimeters), ώστε να εξασφαλίζεται επαρκής αντοχή σε κάμψη,
- ο προσανατολισμός εκτύπωσης, με στόχο τη βελτιστοποίηση της αντοχής κατά τις κύριες διευθύνσεις φόρτισης.

Ιδιαίτερη προσοχή δόθηκε στη σχεδίαση περιοχών σύνδεσης, όπως οπές για βίδες και έδρες εδράνων, οι οποίες τροποποιήθηκαν γεωμετρικά ώστε να λαμβάνουν υπόψη τις ανοχές της προσθετικής κατασκευής και να μειώνουν την ανάγκη εκτεταμένης μετεπεξεργασίας.

### 5.3 Κατασκευαστικοί περιορισμοί και πρακτικά ζητήματα

Παρά τα πλεονεκτήματα της τρισδιάστατης εκτύπωσης, η μέθοδος συνοδεύεται από συγκεκριμένους περιορισμούς, οι οποίοι ελήφθησαν υπόψη στον μηχανολογικό σχεδιασμό. Ενδεικτικά, οι ανομοιογένειες στην αντοχή μεταξύ των στρώσεων (anisotropy), η πιθανότητα παραμορφώσεων κατά την ψύξη και οι περιορισμοί στην ακρίβεια διαστάσεων επηρέασαν τη διαμόρφωση της τελικής γεωμετρίας των εξαρτημάτων.

Για την αντιμετώπιση των παραπάνω ζητημάτων, εφαρμόστηκαν συντηρητικές σχεδιαστικές επιλογές, όπως η αποφυγή πολύ λεπτών τοιχωμάτων, η ενίσχυση κρίσιμων περιοχών και η πρόβλεψη ανοχών στις διεπαφές συναρμολόγησης. Με τον τρόπο αυτό διασφαλίζεται η λειτουργική αξιοπιστία του μηχανισμού, ακόμη και υπό τις εγγενείς αβεβαιότητες της προσθετικής κατασκευής.

### 5.4 Συναρμολόγηση και αξιολόγηση κατασκευής

Μετά την εκτύπωση, τα επιμέρους μηχανικά μέρη συναρμολογήθηκαν σε πλήρες σύστημα, επιτρέποντας την πρακτική αξιολόγηση της γεωμετρικής ακρίβειας, της συναρμογής και της μηχανικής συμπεριφοράς του βραχίονα. Η διαδικασία συναρμολόγησης ανέδειξε σημεία όπου απαιτούνται περαιτέρω βελτιώσεις, όπως προσαρμογές ανοχών ή τοπική ενίσχυση εξαρτημάτων, τα οποία τροφοδοτούν την επόμενη επαναληπτική φάση σχεδίασης.

Η κατασκευαστική διαδικασία, σε συνδυασμό με την αρθρωτή σχεδίαση, επιτρέπει την ταχεία μετάβαση από το θεωρητικό μηχανολογικό μοντέλο σε λειτουργικό πρωτότυπο, επιβεβαιώνοντας την καταλληλότητα της επιλεγμένης προσέγγισης για ερευνητικούς και εκπαιδευτικούς σκοπούς.

## 6. Τρέχουσα κατάσταση και μελλοντικές μηχανολογικές βελτιώσεις

Στο παρόν στάδιο της ανάπτυξης, ο μηχανολογικός σχεδιασμός του ρομποτικού βραχίονα έχει ολοκληρωθεί σε επίπεδο λειτουργικού πρωτοτύπου. Έχει υλοποιηθεί η βασική αρθρωτή αρχιτεκτονική των έξι βαθμών ελευθερίας, έχουν σχεδιαστεί και κατασκευαστεί τα κύρια φέροντα μηχανικά μέρη, ενώ έχει πραγματοποιηθεί αρχική αξιολόγηση της συναρμογής και της μηχανικής συμπεριφοράς του συστήματος.

Η εφαρμογή παραμετρικής σχεδίασης και γενετικού σχεδιασμού επέτρεψε την ανάπτυξη γεωμετριών προσαρμοσμένων στις μηχανικές απαιτήσεις κάθε συνδέσμου, ενώ η χρήση προσθετικής κατασκευής κατέστησε δυνατή τη γρήγορη επαναληπτική βελτίωση των επιμέρους εξαρτημάτων. Παράλληλα, η διαδικασία συναρμολόγησης ανέδειξε πρακτικά ζητήματα, όπως ανοχές σύνδεσης και τοπικές ανάγκες ενίσχυσης, τα οποία αποτελούν πολύτιμη ανατροφοδότηση για τα επόμενα στάδια σχεδιασμού.

Σε μελλοντικό στάδιο της εργασίας, προγραμματίζεται η περαιτέρω βελτίωση της μηχανολογικής δομής μέσω λεπτομερούς ανάλυσης αντοχής και παραμορφώσεων, καθώς και η βελτιστοποίηση επιμέρους συνδέσμων με βάση πραγματικά δεδομένα λειτουργίας. Οι βελτιώσεις αυτές αναμένεται να ενισχύσουν την ακρίβεια, την ακαμψία και τη συνολική αξιοπιστία του ρομποτικού βραχίονα.

## 7. Συμπεράσματα μηχανολογικού μέρους

Στο μηχανολογικό μέρος της παρούσας εργασίας παρουσιάστηκε η ολοκληρωμένη διαδικασία σχεδίασης και ανάπτυξης ενός αρθρωτού ρομποτικού βραχίονα έξι βαθμών ελευθερίας, με στόχο τη διαχείριση ωφέλιμου φορτίου έως 2 kg και τη λειτουργία σε τρισδιάστατο χώρο. Ο σχεδιασμός βασίστηκε σε αρχές αρθρωτής αρχιτεκτονικής, παραμετρικής σχεδίασης και προσθετικής κατασκευής, επιτρέποντας την ευέλικτη και επαναληπτική εξέλιξη του μηχανισμού.

Η ανάλυση φορτίων και η εφαρμογή γενετικού σχεδιασμού συνέβαλαν στον εντοπισμό κρίσιμων περιοχών καταπόνησης και στη βελτίωση της κατανομής υλικού στους φέροντες συνδέσμους. Παράλληλα, η κατασκευαστική διαδικασία μέσω τρισδιάστατης εκτύπωσης απέδειξε την καταλληλότητά της για την υλοποίηση λειτουργικών πρωτοτύπων με χαμηλό κόστος και αυξημένη σχεδιαστική ευελιξία.

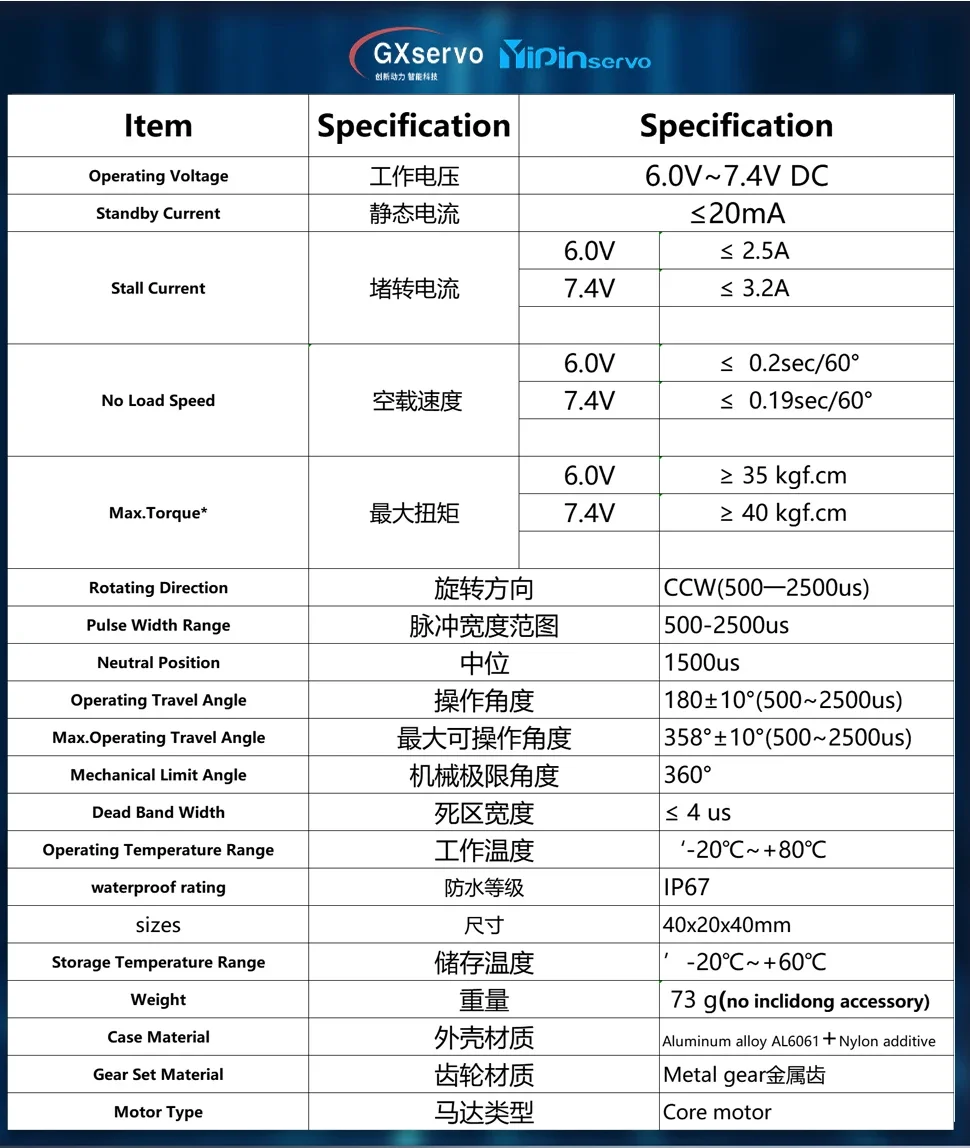
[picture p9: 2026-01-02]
Robotic_Arm_Project/Hardware/GXservo datasheet.webp

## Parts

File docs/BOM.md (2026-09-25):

# Bill of Materials (BOM)

## System performance (estimated)
| Metric | Value | Notes |
|---|---|---|
| Payload @1 m | **~3–4 kg** continuous | after subtracting arm self-weight; ~19 kg momentary/stall |
| Joint speed | **~8.3°/s** | servo 300°/s ÷ 36; 90° in ~11 s |
| Joint torque (pitch, differential) | **~64 N·m** continuous / ~214 N·m stall | 2× actuators add |
| Arm self-weight | **4–5 kg** | CoM ~0.5 m assumed |
| Actuator | servo 40 kg + 1:36 planetary | continuous-rotation servo + AS5600 |

> Speed/torque trade-off: 1:36 gives high torque but is slow. A 1:18
> variant would double speed with still-ample torque (~10 kg payload gross).

Master components list for the robotic arm — single source of truth.
Add items as they are chosen/ordered. Quantities are per full arm unless
noted. Keep in sync with `Robotic_Arm_Project/Hardware/`.

Legend: ✅ have it · 🛒 to order · ❓ to decide

---

## Actuators

### Servo — QY3240MG pro (40 kg, continuous rotation)
| Field | Value |
|---|---|
| Model | QY3240MG pro |
| Type | **Continuous rotation**, digital, metal gear (copper & aluminum) |
| Torque (stall) | 35 kg·cm @6V · 38 kg·cm @7.4V |
| Speed (no load) | 0.2 s/60° @6V · 0.19 s/60° @7.4V (≈ 300°/s ≈ 50 rpm) |
| Operating voltage | **5.0–7.4 V** |
| Signal | neutral **~1520 µs**, up to 333 Hz (we drive at 50 Hz) |
| Dead band | 3 µs |
| Size / weight | 40.5 × 40 × 20.2 mm · 73 g |
| Spline | ❓ confirm (typically 25T for this class) |
| Status | ✅ in use |

Notes:
- Measured neutral on the bench: **~1600 µs** (per-servo trim; spec says 1520).
- Bench range used: 500–2500 µs. All servos on the arm are this model.

Quantities (from the electrical components list):
- base: 1 · bone1: 4 · bone2: 4 · end effector: 3 → see
  `Robotic_Arm_Project/Hardware/Electrical Components.md`

---

## Bearings (deep-groove ball, 2RS sealed)

| Bearing | bore × OD × W (mm) | Use (actual) | Status |
|---|---|---|---|
| 6002 2RS | 15 × 32 × 9 | **planet gears** (planet rides on it) | ✅ |
| 6005 2RS | 25 × 47 × 12 | **shafts / joint output axes** (Ø25) | ✅ |
| 6902 2RS | 15 × 28 × 7 | ❓ TBD | ✅ |
| 6004 2RS | 20 × 42 × 12 | ❓ TBD | ✅ |
| 6208 2RS | 40 × 80 × 18 | ❓ likely base rotation | ✅ |

## Shafts / hubs (Ø = bearing bore, h7 fit)

Large bores → the bearing is usually the **joint pivot**: outer race held by
one part, a hub on the inner race rotates. So the "shaft" is often a hub /
short stub, not a long steel rod (and the bore can pass cables through).

| Joint | Ø (=bore) | Solid shaft or hub? | Status |
|---|---|---|---|
| base | 40 | hub-in-bore (hollow → cabling) | ❓ |
| bone1 | 25 | ❓ | ❓ |
| bone2 | 20 | ❓ | ❓ |
| wrist | 15 | ❓ | ❓ |

## Drivetrain — planetary gearbox (per joint)

**2-stage planetary, 1:6 × 1:6 = 1:36 total.** Output shaft Ø25 on a
**6005** bearing. **AS5600 on the output** → true joint angle after
reduction.

Performance (servo QY3240MG 40 kg + 1:36, ~0.8 efficiency):
| | Servo | Output (÷36) |
|--|---|---|
| Speed (no-load) | ~300°/s | **~8.3°/s** (90° in ~11 s) |
| Torque (stall) | 38 kg·cm | **~1090 kg·cm ≈ 107 N·m** (≈35 N·m continuous) |

> Trade-off: huge torque, slow. If more speed is wanted, a 1:18 variant
> (1:6 × 1:3) doubles output speed with still-ample torque.

Planetary (actual) — **helical, mₙ=1, helix 30°, 20° PA**:
| Element | Teeth | Hand |
|---|---|---|
| Sun | 16 | L |
| Planet (×3) | 32 | R |
| Ring | 80 | R |
- Ratio = 1 + 80/16 = 6.0 ✓ · 3 planets: (16+80)/3 = 32 ✓
- Pitch Ø (mₜ=1.1547): sun 18.48 · planet 36.95 · ring 92.38 mm; center
  distance sun↔planet = 27.7 mm

## Gears — differentials
Bevel gears: **module 1, z=100, 20° PA** → pitch Ø 100 mm, @90°.

| Use | Type | module / teeth | bore | Status |
|-----|---|---|---|---|
| base differential | bevel @90° | m1 / z100 / 20° PA | DIN 5480 spline | ✅ in use |
| wrist differential | bevel @90° | m1 / z100 / 20° PA | DIN 5480 spline | ✅ in use |

## Couplings
_bore = shaft Ø; interface = servo spline. TBD._

| From → To | Type | bore | Qty | Status |
|---|---|---|-----|---|
| servo → shaft | | | | ❓ |

---

## Electronics

| Part | Role | Interface | Qty | Status |
|---|---|---|-----|---|
| Raspberry Pi 4 (4 GB) | onboard ROS 2 node/bridge | — | 1 | ✅ |
| ESP32 | per-segment controller (planned PCBs) | — | per segment | ❓ |
| PCA9685 (16-ch, 12-bit PWM) | servo driver | I²C (0x40) | 1 | ✅ |
| TCA9548A (1→8 I²C mux) | fan out same-address AS5600 | I²C (0x70) | 1 | ✅ |
| AS5600 (12-bit magnetic encoder) | joint angle feedback | I²C (0x36, via mux) | 6 | ✅ |
| ADS1115 (16-bit ADC) | reads analog force sensors | I²C (0x48) | 5 | ✅ |
| FSR402 (force-sensitive resistor) | gripper contact/force | analog → ADS1115 | 2 | ✅ |
| KUAIQU SPS-C3010 PSU | main supply, 30 V/10 A, shows A | mains | 1 | ✅ |
| XY5008E DC-DC buck (6–55V, 5A, CC/CV) | step down to servo/logic rail | — | 2 | ✅ |

Notes:
- **AS5600 ×6** = one per DOF; all share I²C address 0x36 → the **TCA9548A**
  selects one at a time (why the mux is needed).
- **ADS1115 + FSR402** = gripper force/contact sensing (analog FSR → 16-bit
  ADC over I²C). Out of scope for current motion work.
- All I²C devices share the same bus (Pi now / ESP32 later): PCA9685 0x40,
  TCA9548A 0x70, ADS1115 0x48, AS5600 0x36 (behind mux).

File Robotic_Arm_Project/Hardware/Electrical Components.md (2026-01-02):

# Electrical Components

## Power Management

* 1x KUAIQU SPS-C3010 DC Ρεγουλαρη Πηγή Ενέργειας 30V10A 300W Ρυθμιζόμενη
* 2x XY5008E DC DC Buck Step-down Converter CC CV 6-55V 5A 

## Programmable and logical Components

* 1x PCA9685 16 Channel 12-bit PWM Servo motor Driver I2C Module Robot
* Raspberry Pi 4 Model B 4GB

## Wiring Power OR Signal

* 3 Pin A, 22 AWG(Signal)
* 2 Pin, red black, 18AWG, 5m-16.4ft(Power)

## Servo Motors

* (base)  1x GXservo 40kgMG 180 Degree (100mm)

* (bone1) 4x GXservo 40kgMG 180 Degree (120mm)

* (bone2) 4x GXservo 40kgMG 270 Degree (150mm)

* (end effector) (567mm)

&nbsp;	\* 1x GXservo 40kgMG 180 Degree

&nbsp;	\* 1x GXservo 40kgMG 180 Degree

&nbsp;	\* 1x GXservo 40kgMG 180 Degree

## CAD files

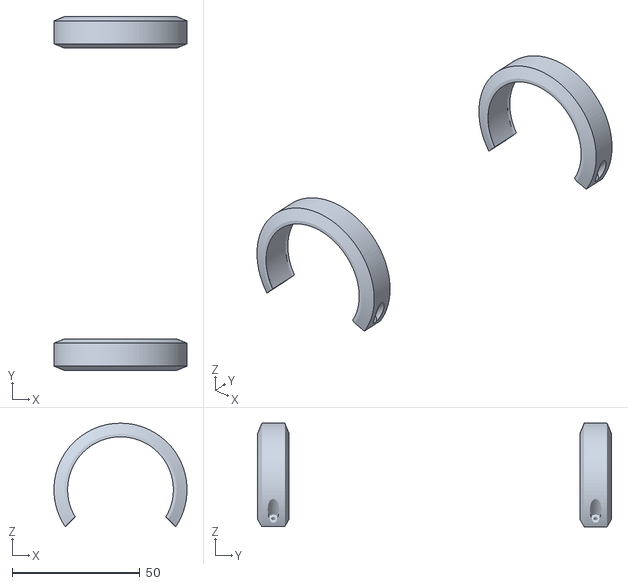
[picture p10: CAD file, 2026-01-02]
Robotic_Arm_Project/3D printing/Bearing holders/Bearing holders Bone1 v2.stl
52.0 x 138.4 x 40.5

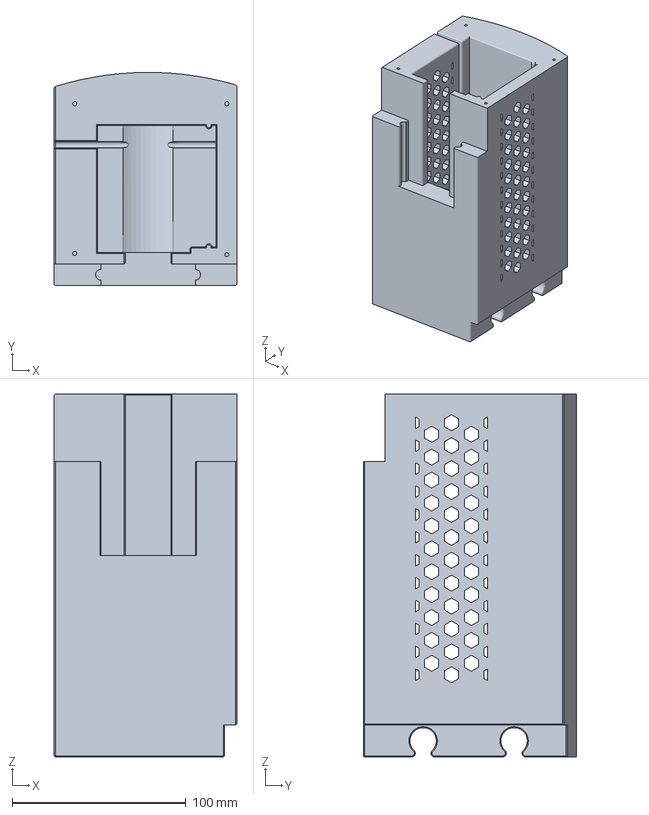
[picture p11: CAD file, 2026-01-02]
Robotic_Arm_Project/3D printing/Big Base/Right down Base v14.3mf
105.2 x 122.9 x 209.2 mm

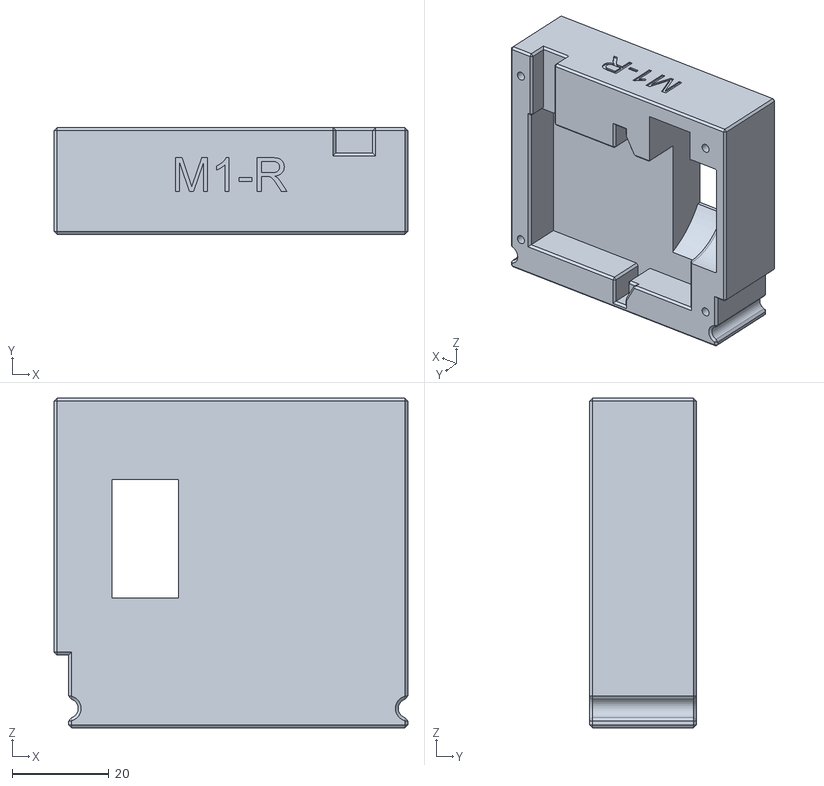
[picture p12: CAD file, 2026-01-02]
Robotic_Arm_Project/3D printing/Caps/Module 1 Caps/Module 1 Right Cap v27.stl
73.0 x 22.0 x 68.0

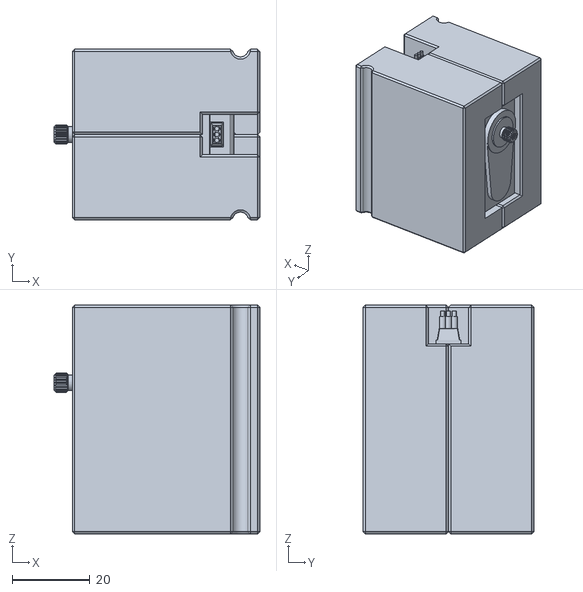
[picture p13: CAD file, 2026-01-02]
Robotic_Arm_Project/3D printing/Caps/Module 4/Module 4.stl
53.0 x 44.0 x 59.0

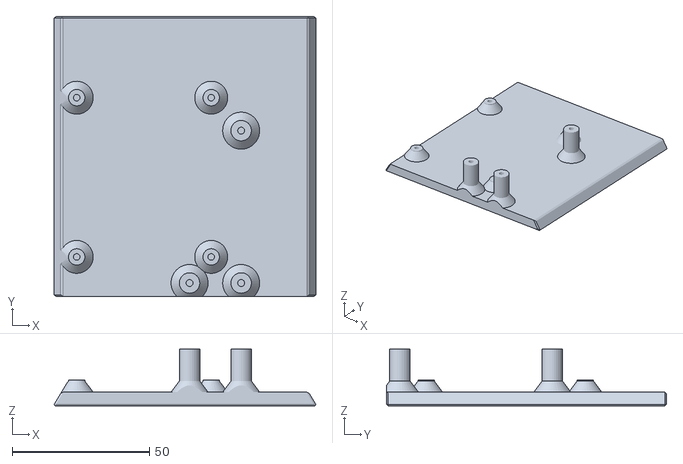
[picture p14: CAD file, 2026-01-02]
Robotic_Arm_Project/3D printing/Electronics Holder/Electronics Holder.stl
95.4 x 102.0 x 20.6

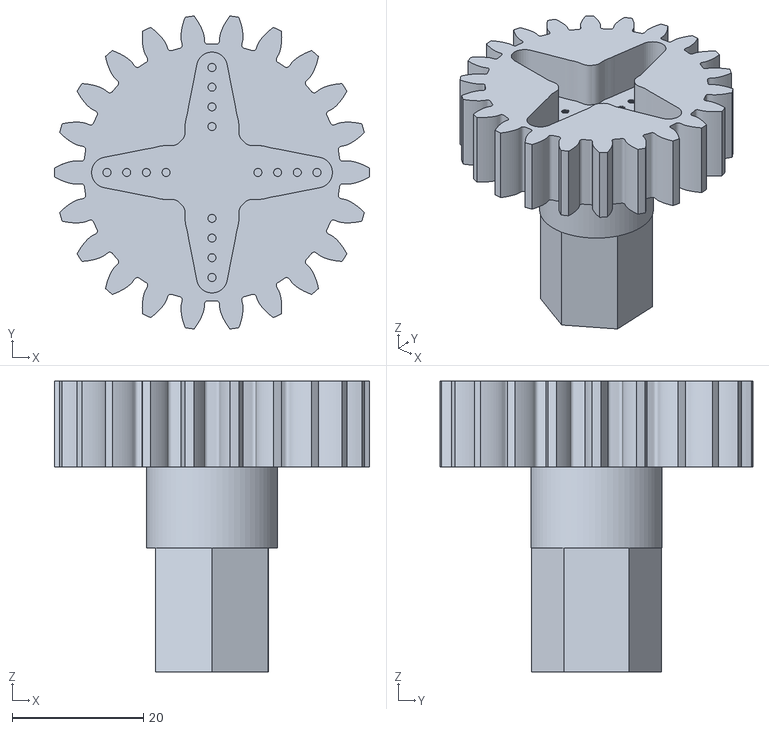
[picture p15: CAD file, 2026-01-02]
Robotic_Arm_Project/3D printing/Gears/Spur Gear (22 teeth) shaft G1.stl
48.0 x 47.7 x 44.3

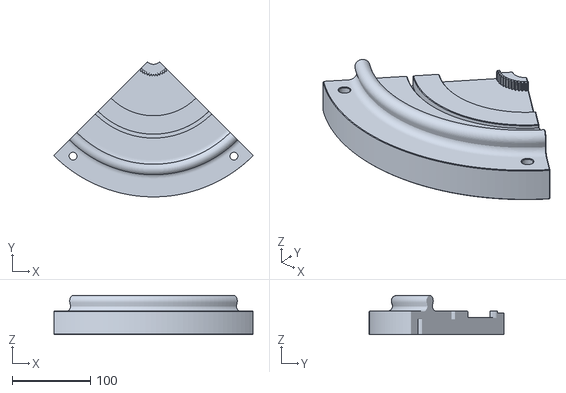
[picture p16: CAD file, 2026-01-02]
Robotic_Arm_Project/3D printing/Rotating Base/Rotating base 2 v27.stl
253.7 x 171.8 x 50.0

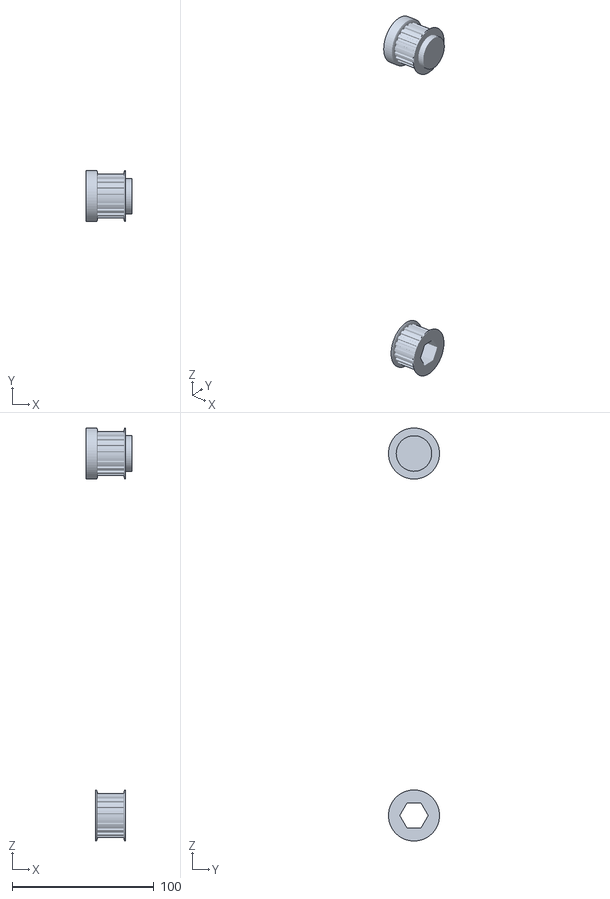
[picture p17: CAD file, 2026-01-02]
Robotic_Arm_Project/3D printing/Timing Belt/Timing belt system v7.stl
32.5 x 36.0 x 290.9

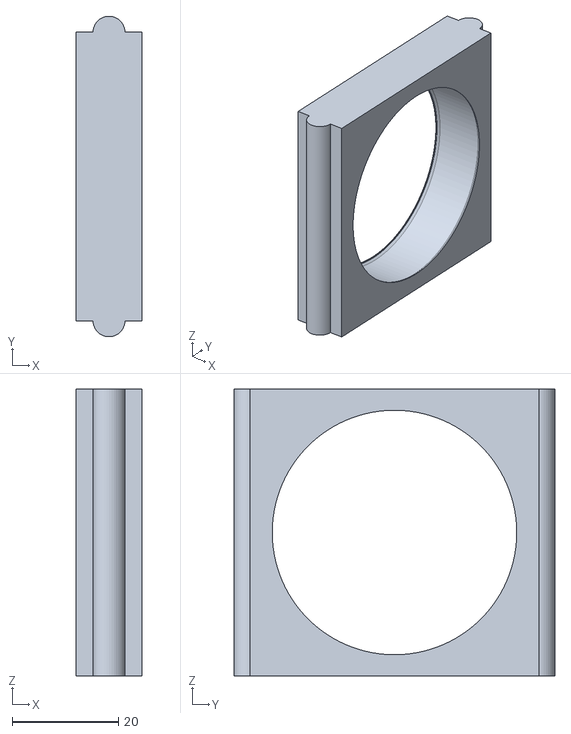
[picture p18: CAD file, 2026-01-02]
Robotic_Arm_Project/3D printing/Bearing holders/Bearing holder v12.stl
12.4 x 60.3 x 54.0

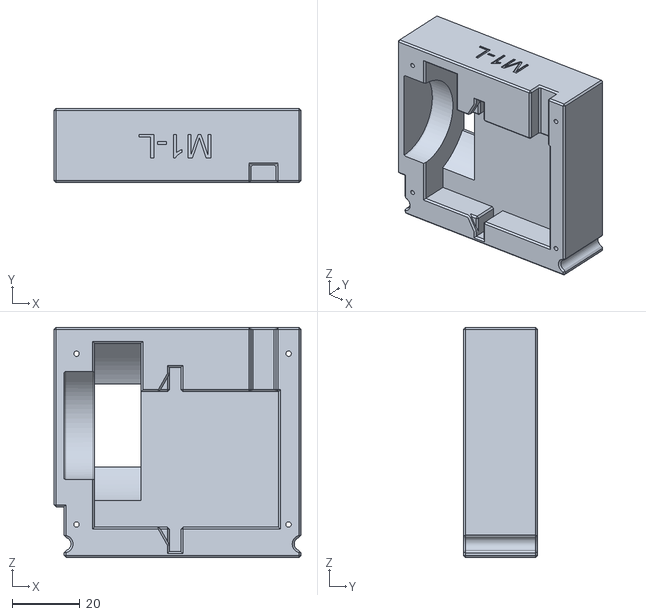
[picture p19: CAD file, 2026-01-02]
Robotic_Arm_Project/3D printing/Caps/Module 1 Caps/Module 1 Left Cap v29.stl
73.0 x 22.0 x 68.0

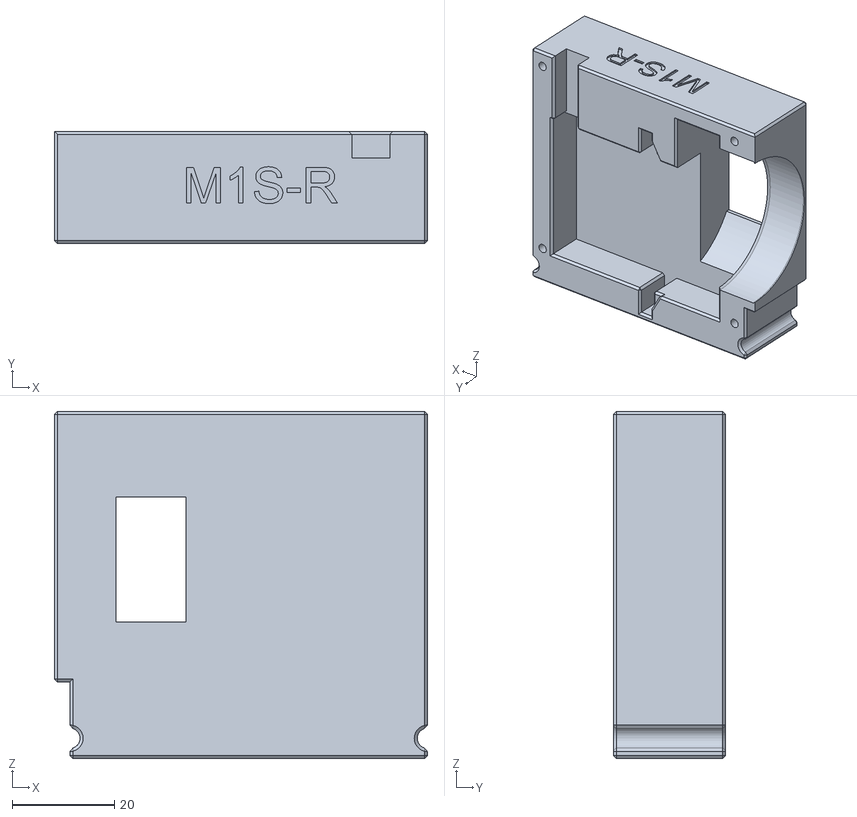
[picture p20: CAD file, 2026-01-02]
Robotic_Arm_Project/3D printing/Caps/Module 1 Shaft Caps/Module 1 && Shaft RIGHT v10.stl
73.0 x 22.0 x 68.0

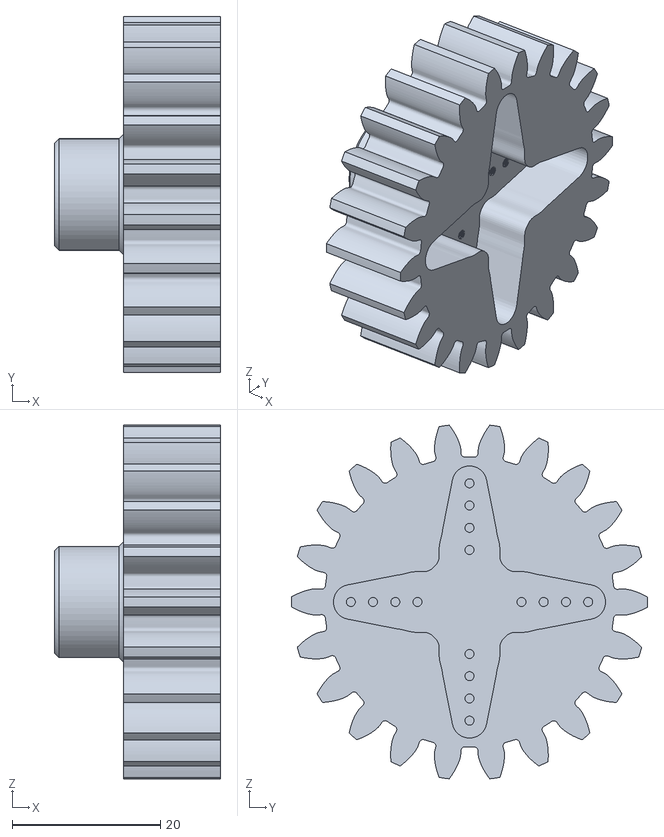
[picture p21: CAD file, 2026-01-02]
Robotic_Arm_Project/3D printing/Gears/4h_mod_gear_8.2deg.stl
22.4 x 48.0 x 47.7

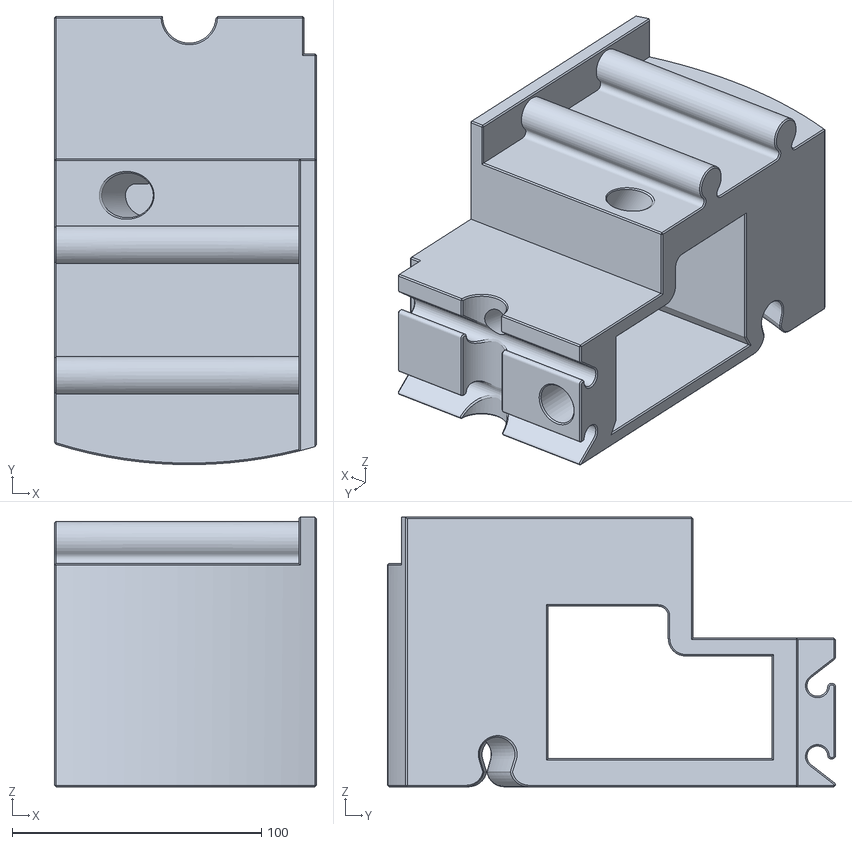
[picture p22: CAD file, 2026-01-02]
Robotic_Arm_Project/3D printing/Big Base/Left down Base v7.stl
105.2 x 180.0 x 108.3

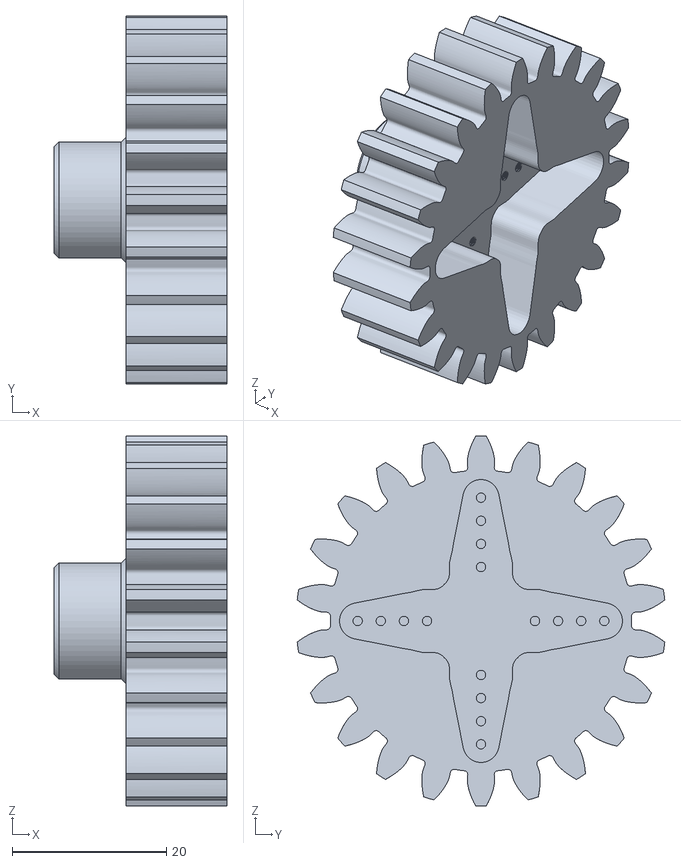
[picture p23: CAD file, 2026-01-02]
Robotic_Arm_Project/3D printing/Gears/4h_mod_gear.stl
22.4 x 47.7 x 48.0

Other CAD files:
Robotic_Arm_Project/3D printing/Caps/Module 1 Shaft Caps/Module 1 && Shaft LEFT v11.stl
Robotic_Arm_Project/3D printing/Big Base/Right up Base v7.stl
Robotic_Arm_Project/3D printing/Rotating Base/Rotating base fastener v31.stl
Robotic_Arm_Project/3D printing/Big Base/Component13 v1.stl
Robotic_Arm_Project/3D printing/Big Base/Left up Base v13.stl
Robotic_Arm_Project/3D printing/Big Base/Right down Base v14.stl
Robotic_Arm_Project/3D printing/Gears/4h_mod_gear_rotating_base.stl
Robotic_Arm_Project/3D printing/Rotating Base/Component13 v1.stl
Robotic_Arm_Project/3D printing/Rotating Base/Rotating base 3 v29.stl
Robotic_Arm_Project/3D printing/Rotating Base/Rotating base 4 v30.3mf
Robotic_Arm_Project/3D printing/Rotating Base/Rotating base 4 v30.stl
Robotic_Arm_Project/3D printing/Rotating Base/Rotating base circle v30.stl
Robotic_Arm_Project/3D printing/Rotating Base/Rotating base v26.stl
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

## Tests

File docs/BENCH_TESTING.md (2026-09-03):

# Bench Testing — Speed & Current (Pi + PCA9685)

Practical guide for the current setup: **Raspberry Pi (Ubuntu Server) →
PCA9685 → servo/gearbox**, no PCB/ESP32 yet. Goal: measure each gearbox's
**speed** and **current draw** ("how much it eats").

## 0. The setup right now

```
  PC/laptop ──SSH──► Raspberry Pi (Ubuntu Server) ──I²C──► PCA9685 ──PWM──► servo ─► gearbox
                          (runs the code)                    ▲
                                                             │ servo V+ from the
                     KUAIQU PSU (servo rail, shows V & A) ───┘ high-current rail
```

- You **write code on your PC** (in this repo), push to GitHub, and **pull
  it on the Pi**. You then **SSH into the Pi** and run the tool there —
  the Pi is what physically talks to the PCA9685 over I²C.
- The PCA9685's **V+ (servo power)** comes from the **KUAIQU PSU**, whose
  display shows the **current (A)** the servos draw — that is your current
  measurement, no extra sensor needed.
- PCA9685 **logic (VCC)**, **SDA**, **SCL**, **GND** go to the Pi. The
  servo-power ground and the Pi ground **must be joined** (common GND).

## 1. Get the repo onto the Pi (once)

SSH in from your PC:
```bash
ssh <user>@<pi-ip-address>
```
Then clone this repo on the Pi:
```bash
sudo apt update && sudo apt install -y git python3-pip i2c-tools
git clone https://github.com/FotisRousogiannis/Robotic-Arm.git
cd Robotic-Arm
```
Enable I²C (Ubuntu Server — no raspi-config):
```bash
sudo nano /boot/firmware/config.txt     # add line:  dtparam=i2c_arm=on
sudo usermod -aG i2c $USER
sudo reboot
```
After reboot, install the driver lib and confirm the chip is seen:
```bash
pip install adafruit-circuitpython-pca9685 adafruit-blinka
i2cdetect -y 1        # expect 0x40 (PCA9685)
```

### Updating the code later
Whenever we change the code here, on the Pi just:
```bash
cd ~/Robotic-Arm && git pull
```

## 2. How you send commands

You type commands in the **SSH terminal on the Pi**. They run
`software/tools/servo_test.py`, which sends PWM to the PCA9685. Example —
first make sure it responds (safe, no motion needed to check wiring):
```bash
cd ~/Robotic-Arm/software/tools
python3 servo_test.py set --channel 9 --angle 135 --min 0 --max 270
```
> On the Pi with the PCA9685 wired, this moves the servo. On your PC
> (no chip) the same command runs in SIMULATION and just prints the pulse.

## 3. Speed test

Move a joint end-to-end at a controlled rate; the tool reports the
effective deg/s:
```bash
# 90 -> 180 deg at 60 deg/s on channel 9:
python3 servo_test.py move --channel 9 --start 90 --end 180 \
        --speed 60 --min 0 --max 270
```
- Try increasing `--speed` until the servo can't keep up (the *effective*
  deg/s stops rising) — that's the gearbox's practical top speed.
- Time a full range both directions to check it's symmetric.

## 4. Current draw test ("πόσο τρώει")

Read **Amps on the KUAIQU PSU display** during three conditions:

| Condition | How | Read |
|---|---|---|
| **Idle/holding** | `hold` at a fixed angle | steady A |
| **Moving** | `move` slowly across the range | A while moving |
| **Stall (peak)** | gently block the output by hand for a moment* | peak A |

```bash
# Hold at 135 deg for 10 s and read the steady current:
python3 servo_test.py hold --channel 9 --angle 135 --seconds 10 --min 0 --max 270

# Slow move to see current rise under load:
python3 servo_test.py move --channel 9 --start 90 --end 180 \
        --speed 15 --min 0 --max 270
```
\* Stall test: only briefly — stall current is high and heats the servo.
Note the peak, then release:
```bash
python3 servo_test.py release --channels 9
```

Record for each gearbox: holding A, moving A, stall A, and deg/s. That
tells you the per-servo budget and sizes the servo power rail (sum of
simultaneous movers × their moving current, with headroom for stalls).

## 5. Differential gearboxes

For the differential joints, test the two motors **together** so the
gearbox sees realistic combined load:
```bash
python3 servo_test.py diff --a 9 --b 10 --pitch 15 --roll 0   # pure pitch
python3 servo_test.py diff --a 9 --b 10 --pitch 0  --roll 15  # pure roll
```
Watch the PSU current for each mode — differentials can draw more when
both motors oppose each other.

---
For a proper logged current curve later, add an **INA219** on the servo
rail (I²C) and we can have the tool read and plot it automatically.

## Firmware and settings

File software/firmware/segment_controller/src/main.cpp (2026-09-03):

// Per-segment ESP32 controller for the robotic arm.
//
// Local stack on one PCB:
//   * PCA9685  -> servo PWM (open-loop angle command)
//   * TCA9548A -> selects one AS5600 magnetic encoder at a time
//   * AS5600   -> true joint angle feedback (0..360 deg)
//
// Comms: a simple line-based SERIAL protocol over USB (115200 baud), so
// you can test the wrist and gearboxes immediately. The higher-level
// host link (micro-ROS / WiFi / serial-to-ROS bridge) can be layered on
// top later without changing the local control below.
//
// Serial commands (newline-terminated):
//   P <axis> <deg>     set target angle for one axis (open-loop servo)
//   H                  home all axes (servo center)
//   E                  print all encoder angles (deg)
//   M <a> <b> <p> <r>  differential mix test: two servo channels a,b
//                      from pitch p and roll r (deg)
//   R <axis>           release one axis servo (stop PWM)
//   ?                  print segment info
//
// Everything here is CALIBRATABLE via include/config.h — the wiring and
// limits are placeholders until measured on the real PCB.

#include <Arduino.h>
#include <Wire.h>
#include <Adafruit_PWMServoDriver.h>
#include "config.h"

Adafruit_PWMServoDriver pca(PCA9685_ADDR);

// ---- TCA9548A: select exactly one downstream channel ----
static void muxSelect(uint8_t channel) {
  Wire.beginTransmission(TCA9548_ADDR);
  Wire.write(1 << channel);
  Wire.endTransmission();
}

// ---- AS5600: read raw angle (0..4095) on the currently selected mux ch ----
static bool as5600ReadRaw(uint16_t& out) {
  Wire.beginTransmission(AS5600_ADDR);
  Wire.write(0x0C);  // RAW ANGLE high register
  if (Wire.endTransmission(false) != 0) return false;
  if (Wire.requestFrom((int)AS5600_ADDR, 2) != 2) return false;
  uint16_t hi = Wire.read();
  uint16_t lo = Wire.read();
  out = ((hi << 8) | lo) & 0x0FFF;
  return true;
}

// Encoder angle for an axis, in degrees, offset/invert applied.
static bool readAxisAngle(int axis, float& deg) {
  const AxisConfig& a = AXES[axis];
  muxSelect(a.mux_channel);
  uint16_t raw;
  if (!as5600ReadRaw(raw)) return false;
  float angle = raw * (360.0f / 4096.0f);
  if (a.encoder_invert) angle = 360.0f - angle;
  angle -= a.encoder_offset;
  deg = angle;
  return true;
}

// ---- PCA9685: command a servo channel to an angle ----
static uint16_t usToTicks(float us) {
  // 12-bit resolution over the PWM period (1e6/freq microseconds).
  float period_us = 1000000.0f / PWM_FREQ_HZ;
  float ticks = (us / period_us) * 4096.0f;
  if (ticks < 0) ticks = 0;
  if (ticks > 4095) ticks = 4095;
  return (uint16_t)ticks;
}

static void setServoAngle(uint8_t channel, float angle,
                          float amin, float amax,
                          uint16_t pmin, uint16_t pmax) {
  if (angle < amin) angle = amin;
  if (angle > amax) angle = amax;
  float frac = (amax > amin) ? (angle - amin) / (amax - amin) : 0.0f;
  float us = pmin + frac * (pmax - pmin);
  pca.setPWM(channel, 0, usToTicks(us));
}

static void setAxis(int axis, float angle) {
  const AxisConfig& a = AXES[axis];
  setServoAngle(a.servo_channel, angle, a.servo_min_angle, a.servo_max_angle,
                a.pulse_min_us, a.pulse_max_us);
}

// ---- Serial command handling ----
static void printInfo() {
  Serial.print(F("segment="));
#ifdef SEGMENT_NAME
  Serial.print(F(SEGMENT_NAME));
#else
  Serial.print(F("unknown"));
#endif
  Serial.print(F(" axes="));
  Serial.println(NUM_AXES);
  for (int i = 0; i < NUM_AXES; i++) {
    Serial.printf("  [%d] %s servo=ch%u enc=mux%u range=%.0f..%.0f\n",
                  i, AXES[i].name, AXES[i].servo_channel, AXES[i].mux_channel,
                  AXES[i].servo_min_angle, AXES[i].servo_max_angle);
  }
}

static void handleLine(char* line) {
  char cmd = line[0];
  switch (cmd) {
    case 'P': {  // P <axis> <deg>
      int axis; float deg;
      if (sscanf(line + 1, "%d %f", &axis, &deg) == 2 &&
          axis >= 0 && axis < NUM_AXES) {
        setAxis(axis, deg);
        Serial.printf("OK P %d %.1f\n", axis, deg);
      } else Serial.println(F("ERR P <axis> <deg>"));
      break;
    }
    case 'H': {  // home all (center of each servo range)
      for (int i = 0; i < NUM_AXES; i++)
        setAxis(i, (AXES[i].servo_min_angle + AXES[i].servo_max_angle) * 0.5f);
      Serial.println(F("OK H"));
      break;
    }
    case 'E': {  // read all encoders
      for (int i = 0; i < NUM_AXES; i++) {
        float d;
        if (readAxisAngle(i, d)) Serial.printf("ENC %d %.2f\n", i, d);
        else Serial.printf("ENC %d ERR\n", i);
      }
      break;
    }
    case 'M': {  // differential mix test: M <a> <b> <pitch> <roll>
      int ca, cb; float pitch, roll;
      if (sscanf(line + 1, "%d %d %f %f", &ca, &cb, &pitch, &roll) == 4) {
        // Uses joint3-like 270deg servos centered at 135 by default.
        float center = 135.0f;
        setServoAngle(ca, center + pitch + roll, 0, 270, 500, 2500);
        setServoAngle(cb, center + pitch - roll, 0, 270, 500, 2500);
        Serial.printf("OK M a=%d b=%d p=%.1f r=%.1f\n", ca, cb, pitch, roll);
      } else Serial.println(F("ERR M <a> <b> <pitch> <roll>"));
      break;
    }
    case 'R': {  // release one axis
      int axis;
      if (sscanf(line + 1, "%d", &axis) == 1 && axis >= 0 && axis < NUM_AXES) {
        pca.setPWM(AXES[axis].servo_channel, 0, 0);
        Serial.printf("OK R %d\n", axis);
      } else Serial.println(F("ERR R <axis>"));
      break;
    }
    case '?': printInfo(); break;
    case '\0': break;
    default: Serial.println(F("ERR unknown cmd (P H E M R ?)"));
  }
}

void setup() {
  Serial.begin(115200);
  delay(200);
  Wire.begin(I2C_SDA, I2C_SCL, I2C_HZ);
  pca.begin();
  pca.setPWMFreq(PWM_FREQ_HZ);
  Serial.println(F("segment_controller ready"));
  printInfo();
}

void loop() {
  static char buf[64];
  static uint8_t n = 0;
  while (Serial.available()) {
    char c = (char)Serial.read();
    if (c == '\n' || c == '\r') {
      buf[n] = '\0';
      if (n > 0) handleLine(buf);
      n = 0;
    } else if (n < sizeof(buf) - 1) {
      buf[n++] = c;
    }
  }
}

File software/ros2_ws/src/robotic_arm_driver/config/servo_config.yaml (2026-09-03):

# Servo configuration for the 6-DOF robotic arm (full-arm profile).
#
# The arm has two DIFFERENTIAL mechanisms (base and wrist): in each, two
# servos work together to produce two rotational DOF (pitch + roll) via
# mixing. Independent DOF (yaw, gripper) map 1:1 to a single servo.
#
# Angles are in degrees. pulse_min/pulse_max are the PWM pulse widths (us)
# at the servo's mechanical extremes servo_min_angle/servo_max_angle.
# Every value here is a starting point — CALIBRATE on the real hardware.

servo_driver:
  ros__parameters:
    i2c_bus: 1
    pca9685_address: 0x40
    pwm_frequency: 50

    # Logical DOF exposed on /joint_commands (matched by name).
    joint_names:
      - base_pitch
      - base_roll
      - wrist_pitch
      - wrist_roll
      - wrist_yaw
      - gripper

    # --- Independent (1:1) joints ---
    direct_joints: [wrist_yaw, gripper]
    joints:
      wrist_yaw:
        channel: 8
        invert: false
        min_angle: 0.0
        max_angle: 180.0
        home: 90.0
        pulse_min: 500
        pulse_max: 2500
      gripper:
        channel: 11
        invert: false
        min_angle: 0.0
        max_angle: 180.0
        home: 0.0
        pulse_min: 500
        pulse_max: 2500

    # --- Differential mechanisms ---
    # Motor angles: A = center_a + pitch_gain*pitch + roll_gain*roll
    #               B = center_b + pitch_gain*pitch - roll_gain*roll
    differential_pairs: [base_diff, wrist_diff]
    differentials:
      base_diff:
        channel_a: 0
        channel_b: 1
        joint_pitch: base_pitch
        joint_roll: base_roll
        center_a: 90.0
        center_b: 90.0
        pitch_gain: 1.0
        roll_gain: 1.0
        servo_min_angle: 0.0
        servo_max_angle: 180.0
        pulse_min: 500
        pulse_max: 2500

      wrist_diff:
        channel_a: 9
        channel_b: 10
        joint_pitch: wrist_pitch
        joint_roll: wrist_roll
        center_a: 135.0
        center_b: 135.0
        pitch_gain: 1.0
        roll_gain: 1.0
        servo_min_angle: 0.0
        servo_max_angle: 270.0
        pulse_min: 500
        pulse_max: 2500

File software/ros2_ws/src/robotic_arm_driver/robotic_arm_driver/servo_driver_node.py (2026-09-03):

#!/usr/bin/env python3
"""ROS 2 servo driver node for the robotic arm.

Subscribes to logical joint angle commands and drives GXservo motors
through a PCA9685 16-channel PWM controller over I2C. Supports two kinds
of joints:

* **direct** joints  — one logical DOF -> one servo channel (yaw, gripper)
* **differential** pairs — two servos combine to produce two DOF
  (pitch + roll), as on this arm's base and wrist. Motor angles are:

      A = center_a + pitch_gain*pitch + roll_gain*roll
      B = center_b + pitch_gain*pitch - roll_gain*roll

Topics
------
subscribes:  /joint_commands  (sensor_msgs/JointState)
    positions = target angles in **degrees**, matched to joints by name.
    Joints omitted from a message keep their last commanded value.

On a machine without the PCA9685 libraries the node falls back to a
"simulation" backend that logs the PWM it would send, so the pipeline
can be tested off the robot.
"""

from __future__ import annotations

import rclpy
from rclpy.node import Node
from sensor_msgs.msg import JointState


class ServoBackend:
    """Abstracts the PWM hardware so the node runs on- or off-robot."""

    def __init__(self, node: Node, address: int, frequency: int):
        self._node = node
        self._frequency = frequency
        self._sim = False
        self._pca = None
        try:
            from board import SCL, SDA  # type: ignore
            import busio  # type: ignore
            from adafruit_pca9685 import PCA9685  # type: ignore

            i2c = busio.I2C(SCL, SDA)
            self._pca = PCA9685(i2c, address=address)
            self._pca.frequency = frequency
            node.get_logger().info(
                f'PCA9685 initialised @ 0x{address:02x}, {frequency} Hz')
        except Exception as exc:  # noqa: BLE001
            self._sim = True
            node.get_logger().warn(
                f'PCA9685 unavailable ({exc}); running in SIMULATION mode.')

    def set_pulse_us(self, channel: int, pulse_us: float) -> None:
        if self._sim or self._pca is None:
            self._node.get_logger().info(
                f'[sim] ch{channel:>2} <- {pulse_us:.0f} us')
            return
        period_us = 1_000_000.0 / self._frequency
        duty = int(max(0.0, min(1.0, pulse_us / period_us)) * 0xFFFF)
        self._pca.channels[channel].duty_cycle = duty


def _angle_to_pulse(angle, a_min, a_max, p_min, p_max, invert=False):
    """Map an angle in [a_min, a_max] to a pulse width in [p_min, p_max]."""
    span = a_max - a_min
    clamped = max(a_min, min(a_max, angle))
    frac = 0.0 if span == 0 else (clamped - a_min) / span
    if invert:
        frac = 1.0 - frac
    return p_min + frac * (p_max - p_min)


class ServoDriverNode(Node):
    def __init__(self) -> None:
        super().__init__('servo_driver')

        address = self.declare_parameter('pca9685_address', 0x40).value
        frequency = self.declare_parameter('pwm_frequency', 50).value
        self.declare_parameter('i2c_bus', 1)  # informational

        self._backend = ServoBackend(self, address, frequency)

        # Current target angle for every logical DOF.
        self._targets: dict[str, float] = {}

        self._direct: dict[str, dict] = {}
        self._diffs: list[dict] = []

        self._load_direct_joints()
        self._load_differentials()

        if not self._direct and not self._diffs:
            self.get_logger().error(
                'No joints configured. Did you pass a config YAML?')

        # Drive everything to its home/center pose on startup.
        self._apply_all()

        self._sub = self.create_subscription(
            JointState, 'joint_commands', self._on_command, 10)
        self.get_logger().info(
            f'servo_driver ready — DOF: {sorted(self._targets)}')

    # ------------------------------------------------------------------ config
    def _load_direct_joints(self) -> None:
        names = self.declare_parameter('direct_joints', []).value or []
        for name in names:
            p = f'joints.{name}'
            cfg = {
                'channel': int(self.declare_parameter(f'{p}.channel', 0).value),
                'invert': bool(self.declare_parameter(f'{p}.invert', False).value),
                'min_angle': float(self.declare_parameter(f'{p}.min_angle', 0.0).value),
                'max_angle': float(self.declare_parameter(f'{p}.max_angle', 180.0).value),
                'home': float(self.declare_parameter(f'{p}.home', 90.0).value),
                'pulse_min': float(self.declare_parameter(f'{p}.pulse_min', 500.0).value),
                'pulse_max': float(self.declare_parameter(f'{p}.pulse_max', 2500.0).value),
            }
            self._direct[name] = cfg
            self._targets[name] = cfg['home']

    def _load_differentials(self) -> None:
        pairs = self.declare_parameter('differential_pairs', []).value or []
        for name in pairs:
            p = f'differentials.{name}'
            pitch = self.declare_parameter(f'{p}.joint_pitch', f'{name}_pitch').value
            roll = self.declare_parameter(f'{p}.joint_roll', f'{name}_roll').value
            cfg = {
                'name': name,
                'channel_a': int(self.declare_parameter(f'{p}.channel_a', 0).value),
                'channel_b': int(self.declare_parameter(f'{p}.channel_b', 1).value),
                'joint_pitch': pitch,
                'joint_roll': roll,
                'center_a': float(self.declare_parameter(f'{p}.center_a', 90.0).value),
                'center_b': float(self.declare_parameter(f'{p}.center_b', 90.0).value),
                'pitch_gain': float(self.declare_parameter(f'{p}.pitch_gain', 1.0).value),
                'roll_gain': float(self.declare_parameter(f'{p}.roll_gain', 1.0).value),
                'servo_min_angle': float(self.declare_parameter(f'{p}.servo_min_angle', 0.0).value),
                'servo_max_angle': float(self.declare_parameter(f'{p}.servo_max_angle', 180.0).value),
                'pulse_min': float(self.declare_parameter(f'{p}.pulse_min', 500.0).value),
                'pulse_max': float(self.declare_parameter(f'{p}.pulse_max', 2500.0).value),
            }
            self._diffs.append(cfg)
            self._targets.setdefault(pitch, 0.0)
            self._targets.setdefault(roll, 0.0)

    # ------------------------------------------------------------------ drive
    def _apply_direct(self, name: str) -> None:
        cfg = self._direct[name]
        pulse = _angle_to_pulse(
            self._targets[name], cfg['min_angle'], cfg['max_angle'],
            cfg['pulse_min'], cfg['pulse_max'], cfg['invert'])
        self._backend.set_pulse_us(cfg['channel'], pulse)
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

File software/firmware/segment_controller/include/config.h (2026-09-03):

#pragma once
// Per-segment configuration. Copy/adjust these values for each PCB
// (base, wrist, ...). All angles are in degrees.

#include <stdint.h>

// ---- I2C bus ----
static const int I2C_SDA = 21;   // ESP32 default
static const int I2C_SCL = 22;
static const uint32_t I2C_HZ = 400000;

// ---- Devices ----
static const uint8_t PCA9685_ADDR = 0x40;
static const uint8_t TCA9548_ADDR = 0x70;
static const uint8_t AS5600_ADDR  = 0x36;  // fixed -> needs the mux
static const int PWM_FREQ_HZ = 50;

// ---- Axes on THIS segment ----
// Each axis pairs one servo (PCA9685 channel) with one encoder
// (TCA9548A channel). Order defines the axis index used on serial.
static const int NUM_AXES = 3;   // e.g. base: joints 1,2,3

struct AxisConfig {
  const char* name;
  uint8_t servo_channel;   // PCA9685 output channel
  uint8_t mux_channel;     // TCA9548A channel the AS5600 is on
  float servo_min_angle;   // servo mechanical extremes...
  float servo_max_angle;
  uint16_t pulse_min_us;   // ...at these pulse widths
  uint16_t pulse_max_us;
  float encoder_offset;    // deg subtracted so home reads ~0
  bool  encoder_invert;    // flip encoder direction if needed
};

// NOTE: placeholder wiring — set these from your PCB layout & calibration.
static const AxisConfig AXES[NUM_AXES] = {
  // name          servo mux  smin  smax   pmin  pmax  offset invert
  { "joint1",        0,   0,   0.f, 180.f,  500,  2500,  0.f,  false },
  { "joint2",        1,   1,   0.f, 180.f,  500,  2500,  0.f,  false },
  { "joint3",        2,   2,   0.f, 270.f,  500,  2500,  0.f,  false },
};

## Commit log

2026-01-02 add rest
    [4h_mod_gear.stl, 4h_mod_gear_8.2deg.stl, 4h_mod_gear_rotating_base.stl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]
2026-09-03 Add project README, .gitignore, and clean up repo structure
    - Add comprehensive README documenting the robotic arm thesis project
    - Add .gitignore (Jupyter checkpoints, Python, OS, editor files)
    - Remove leftover test files (test.txt, new test.txt)
    - Fix folder/file typos: Pappers->Papers, Documentaion->Documentation,
    Electircal report.pdf->Electrical report.pdf
    - Untrack committed .ipynb_checkpoints
    Claude-Session: https://claude.ai/code/session_01K1DU6EvU9xmJxGFVTMntPs
2026-09-03 Scaffold ROS 2 workspace with servo driver package
    Add software/ros2_ws with the robotic_arm_driver package: a ROS 2 (rclpy)
    node that subscribes to /joint_commands (JointState, degrees) and drives
    GXservo motors via a PCA9685 over I2C. Includes per-joint channel/limit
    config (servo_config.yaml) and a simulation fallback for development
    without the hardware. Work in progress pending hardware/software details.
    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
    [servo_config.yaml]
2026-09-03 Add differential-aware driver, standalone servo test tool, and docs
    Reflect the real arm architecture (differential base + wrist, Link 1
    pending, wrist-first testing):
    - software/tools/servo_test.py: standalone (no ROS) tool to move, sweep,
    center, release servos and test differential pitch/roll mixing — for
    verifying the wrist and gearboxes now. Simulation fallback off-robot.
    - robotic_arm_driver: rewrite servo node to support direct + differential
    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
    [servo_config.yaml]
2026-09-03 Model distributed ESP32-per-segment control architecture
    Capture the real design: each arm segment has its own PCB (ESP32 +
    PCA9685 + TCA9548A + buck) doing local control, coordinated by an
    Ubuntu Server host over ROS 2.
    - docs/ARCHITECTURE.md: distributed topology diagram, per-segment PCB
    parts table, AS5600-behind-TCA9548A closed-loop feedback, Ubuntu Server
    host note.
    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
2026-09-03 Document micro-ROS as the ESP32<->host link
    - ARCHITECTURE.md: micro-ROS host-link section (agent, per-segment topics,
    UDP/WiFi transport, local closed loop preserved).
    - platformio.ini: add esp32-microros build env (micro_ros_platformio).
    - firmware README: micro-ROS roadmap; note PCB/firmware on hold pending
    boards.
    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
2026-09-03 Add bench testing guide and speed/current test commands
    - servo_test.py: add 'move' (controlled deg/s, timed) and 'hold' commands
    for measuring gearbox speed and current draw.
    - docs/BENCH_TESTING.md: full Pi (Ubuntu Server) + PCA9685 workflow —
    clone repo on the Pi, enable I2C, send commands over SSH, measure speed,
    and read current off the KUAIQU PSU display (idle/moving/stall).
    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
    [servo_test.py]
2026-09-03 Add continuous-rotation servo commands to bench tool
    Continuous servos interpret pulse width as speed, not position. Add:
    - spin: run at speed (-1..1) for N seconds then stop
    - pulse: send a raw microsecond pulse (manual control)
    - stop: send the center/stop pulse
    with configurable center/min/max microseconds.
    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
2026-09-03 Add keyboard teleop for continuous servo (a/d direction, w/s speed)
    Interactive live control of one continuous-rotation servo over SSH:
    a/d spin CCW/CW, w/s step speed up/down, space stop, r release, q quit.
    Reuses Driver + speed mapping from servo_test.py; guards against
    non-TTY stdin.
    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
2026-09-03 Keyboard teleop: hold-to-move, stop by cutting PWM signal
    - Servo now moves ONLY while a/d is held (keyboard auto-repeat); it stops
    automatically ~0.25s after release (configurable via --hold-timeout).
    - Stopping uses release() (duty_cycle=0) instead of the center pulse, so a
    continuous servo whose neutral isn't exactly 1500us actually halts.
    - Ctrl+C also exits cleanly; w/s still set the speed magnitude.
    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
2026-09-03 Fix stop for center-neutral continuous servo
    This servo holds still at the center pulse (1500us) and spins when the
    signal is cut. Stopping now sends the center pulse instead of release(),
    so releasing a/d actually stops it. Update docs accordingly.
    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
    [servo_keyboard.py]
2026-09-03 Add live neutral calibration ([ / ]) to keyboard teleop
    The idle 'stop' pulse must match the servo's true neutral or it creeps.
    Add [ and ] keys to trim --center live (default 5us/step) until the servo
    sits still; the status line shows the current center to reuse via --center.
    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
2026-09-03 Raise hold-mode timeout to 0.5s to bridge terminal key-repeat delay
    Makes hold-to-move (default mode) smoother: the servo keeps moving while
    a/d is held and stops shortly after release, without stuttering during the
    terminal's initial auto-repeat gap.
    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
    [servo_keyboard.py]
2026-09-03 Revert hold-timeout default back to 0.25s
    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
    [servo_keyboard.py]
2026-09-03 Add Greek-layout key support and differential-pair keyboard teleop
    - servo_keyboard.py: accept Greek keyboard characters (α/δ/ς/σ -> a/d/w/s)
    so controls work regardless of active layout.
    - servo_diff_keyboard.py: hold-to-move teleop for a differential pair of
    continuous servos (base/wrist). w/s = pitch (servos together), a/d =
    roll (servos opposed); per-motor neutral (--center-a/-b) and direction
    (--invert-a/-b), +/- speed, space stop.
    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
    [servo_diff_keyboard.py, servo_keyboard.py]
2026-09-03 Default all teleop servos to measured neutral 1600us, range 500-2500
    All servos on the arm are identical, so bake in the calibrated values as
    defaults (single-servo teleop). Overridable per servo if ever needed.
    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
2026-09-03 Default differential to mirrored servos (motor B inverted)
    Confirmed on the base: mirrored mounting needs one motor inverted for
    clean pitch. Make B inverted by default; --invert-b flips it back for
    builds that differ.
    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
    [servo_diff_keyboard.py]
2026-09-03 Add arm_calibration.json and --joint loading for differential teleop
    Single source of truth for bench calibration (servo neutral 1600us, range
    500-2500, per-joint channels and inverts). servo_diff_keyboard.py --joint
    base loads the verified base config; wrist entry stubbed for later.
    Clean up invert-a/invert-b semantics (invert=true means that motor is
    inverted).
    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
    [servo_diff_keyboard.py]
2026-09-06 Add system architecture design doc (distributed ROS 2 + UI + VLM)
    Locked decision: workstation = main compute (ROS 2, UI, VLM, planning,
    sim), Raspberry Pi kept as onboard ROS 2 node/bridge (micro-ROS agent +
    camera), ESP32 per segment via micro-ROS. Documents compute layers, comms
    protocols (DDS / micro-ROS / rosbridge), core topics, manual/autonomous/
    e-stop modes, bench-work reuse, and a phased plan.
    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
2026-09-25 Start BOM: QY3240MG pro continuous servo spec + placeholders
    Master components list. Servo documented (40kg continuous, 5-7.4V, ~1520us
    neutral, 50Hz). Placeholders for bearings/shafts/gears/couplings to fill in
    as parts are confirmed.
    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
2026-09-25 BOM: add electronics (AS5600 x6, TCA9548A, ADS1115, FSR402, buck, PSU)
    Full electronics table with I2C addresses and roles. AS5600 x6 (one per
    DOF) behind the TCA9548A mux; ADS1115+FSR402 for gripper force sensing.
    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
2026-09-25 BOM: add bearings (6902/6002/6004/6005/6208) and shaft/hub table
    Deep-groove 2RS bearings, bores 15-40mm. Proposed joint mapping and note
    that large bores act as joint pivots (hub-in-bore, hollow for cabling).
    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
2026-09-25 BOM: document 2-stage 1:6x1:6 planetary gearbox (1:36) + standard
    Output shaft 25mm on 6005, AS5600 on output. Adds performance figures
    (~8.3 deg/s, ~107 N.m stall) and a standardized planetary tooth set
    (sun 12 / planet 24 / ring 60, 20deg PA).
    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
2026-09-25 Add mechanical standards doc + system performance to BOM
    MECHANICAL_STANDARDS.md: fasteners, bearing set, shaft/hub fits, gear rules
    (20deg PA, module policy, planetary sun12/planet24/ring60, bevel miter 1:1),
    couplings/servo spline interface, differential flange pattern, tolerances,
    file naming convention, I2C map, and open items to confirm.
    BOM: system performance summary (payload ~3-4kg@1m, ~8.3 deg/s, 4-5kg self).
    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
2026-09-25 Lock planetary gears to actual design: helical mn=1, 30deg, 16/32/80
    Correct the placeholder tooth counts to the real CAD: helical gears,
    normal module 1, 30deg helix, sun 16L / planet 32R x3 / ring 80R (1:6).
    Add transverse module, pitch diameters, center distance; note helical
    axial thrust. Mark planetary + planet count confirmed.
    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
2026-09-25 BOM/standards: map bearings by actual function (6002 planets, 6005 shafts)
    6002 carries the planet gears, 6005 the output/joint shafts (Ø25). Other
    bearings (6902/6004/6208) marked TBD pending placement.
    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
2026-09-25 Add mechanical analysis (5kg payload target, gear loading, fixes)
    Full drivetrain analysis: output speed/torque, torque required for 5kg@1m,
    reduction trade-off table, gear tooth loading (the critical limit), helical
    thrust, holding strategy, planet wall note. Conclusion: keep 1:36 (optimal
    for 5kg), but output gears must move to Nylon/PA-CF + wider face and add a
    holding strategy.
    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
2026-09-25 Clarify output interfaces: shaft->bevel via spline, housing->body via ISO 9409-1 flange
    Correct the architecture: gearbox output shaft drives the differential bevel
    gear (spline preferred for low backlash/centering), and the gearbox housing
    mounts to the arm body via an ISO 9409-1 flange. Two separate interfaces.
    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
2026-09-25 Standards: specify metric DIN 5480 spline for shaft->bevel (keep metric)
    Shaft = plain Ø25 k6 journal for 6005 + DIN 5480 involute spline section
    (W 25x1x23x8f / N 25x1x23x9H) for the bevel gear. Note to avoid inch
    McMaster splined shafts which force an inch-bore bearing.
    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
2026-09-25 Lock shaft->bevel as printed DIN 5480 spline (all parts 3D printed)
    All parts printed -> bevel bore is a printed internal DIN 5480 spline onto
    the shaft; no press fit / coupling / locking device. Add full spline values
    for the Fusion generator (m1, z24, 30deg, x-0.05, pitch 24, base 20.78,
    0.1-0.15mm print clearance) and axial retention (shoulder + DIN 471 circlip).
    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
2026-09-25 Spline: use SplineCALC DIN 5480 25x1.25x18 (9H/8f) exact dimensions
    Replace hand-figured m1/z24 with the DIN preferred pair from SplineCALC:
    25 x 1.25 x 18, x1=+0.45/x2=-0.45, pitch 22.5, base 19.486, shaft tip 24.75
    /root 22.444, hub tip 22.5/root 25.25, Le 15mm, backlash 0.038-0.284.
    Module 1.25 gives stronger teeth (good for printed gears). DXF exportable.
    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
2026-09-25 Record differential bevel gears: m1, z100, 20deg PA (pitch dia 100mm)
    Large 100mm pitch diameter lowers tooth force (~740N operating vs 2240N
    stall per gearbox). Bore = DIN 5480 spline. Confirm mating gear teeth/ratio
    and face width next.
    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
